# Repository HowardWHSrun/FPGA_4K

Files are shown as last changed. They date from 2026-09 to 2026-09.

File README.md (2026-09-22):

# FPGA_4K

Shared PCB development for the 4K neural-recording system: working designs, interface decisions, reference boards and acquisition software.

## Start working with the team

**[Team start page](docs/team/README.md)** · **[Setup and daily workflow](CONTRIBUTING.md)** · **[Owners and open work](docs/team/owners-and-work.md)**

| Work | Start here | Status |
|---|---|---|
| FPGA design | [Open the working draft](hardware/fpga-board/README.md) | Imported September 21; incomplete electrical design; **not for manufacture** |
| Carrier and routing boards | [Original reference projects](hardware/README.md) | Preserved references; active baselines and owners to confirm |
| Tasks and layout ownership | [Create a PCB task](https://github.com/HowardWHSrun/FPGA_4K/issues/new?template=pcb-task.yml) | One active layout editor per board |
| Pinout / power / protocol decisions | [Create a decision](https://github.com/HowardWHSrun/FPGA_4K/issues/new?template=interface-decision.yml) | Review with owners on both sides |
| Proposed changes | [Pull requests](https://github.com/HowardWHSrun/FPGA_4K/pulls) | Branch → review → merge → pull |

Use KiCad **10.0.6** for the FPGA handoff. Clone the repository, open the project from your clone, and keep its custom libraries alongside it. Follow [CONTRIBUTING.md](CONTRIBUTING.md) before editing; uploading a draft does not approve its circuit or make `main` fabrication-ready.

## Board overview

### Overall assembly

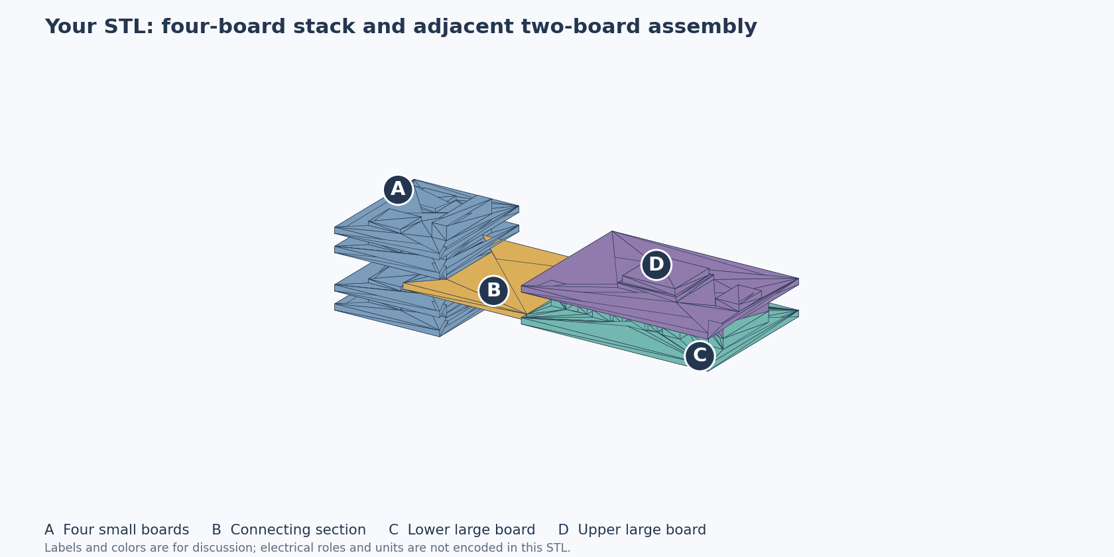
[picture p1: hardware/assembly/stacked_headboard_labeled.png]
Overall stacked-headboard assembly concept


The earlier assembly concept shows the four-board ASIC-carrier stack, routing section and FPGA board. **[Open the 3D model and region guide](hardware/assembly/README.md)** · [Download STL](hardware/assembly/stacked_headboard_original.stl?raw=true). The original model is preserved; dimensions are provisional and its author is unverified.

### Supplied board references

| ASIC carrier reference | LDO/routing reference |
|---|---|
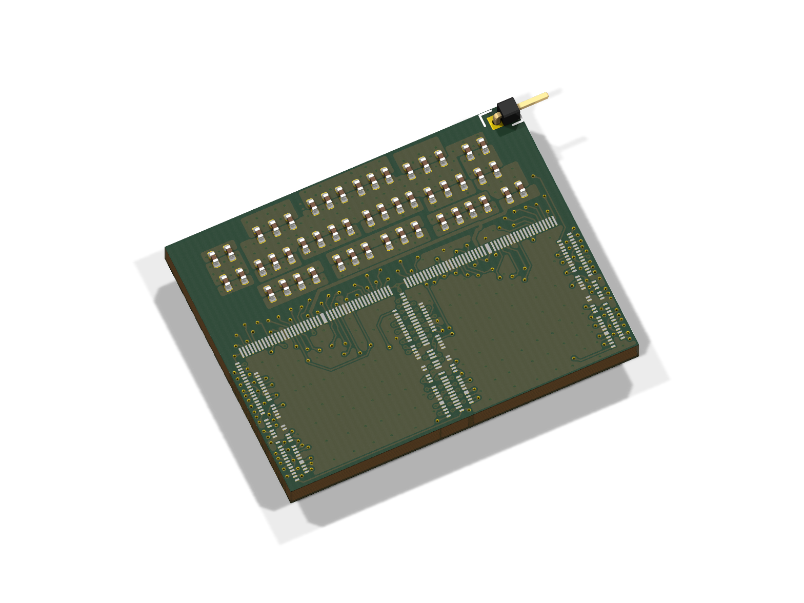
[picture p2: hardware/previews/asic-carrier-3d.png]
Overall view of the supplied two-chip carrier
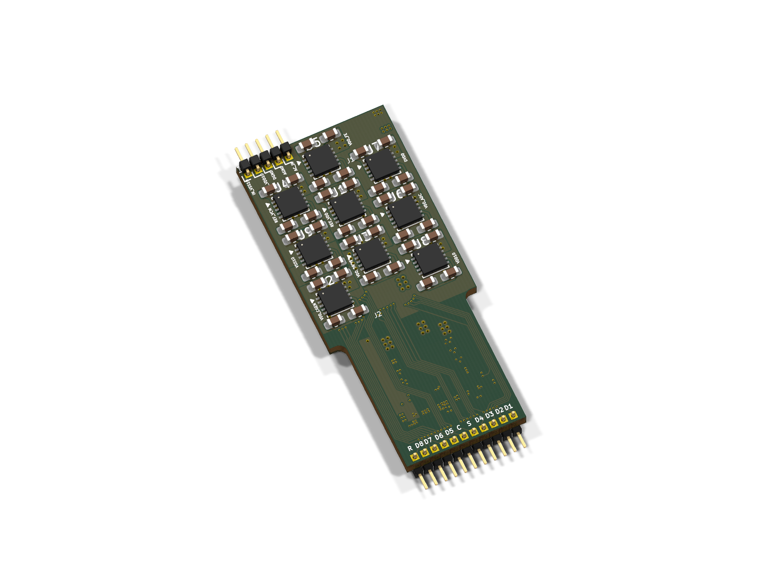
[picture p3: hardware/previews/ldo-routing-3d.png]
Overall view of the supplied LDO and routing board
|  |  |
| Approximately 22 × 17 mm; two chip footprints | Approximately 18.3 × 42 mm; regulator area and signal routing |

These are renders of the supplied reference boards; unavailable custom 3D models are omitted. Open the **[visual hardware overview](hardware/overview.md)** for the system diagram, original assembly photograph, front/back layouts and editable files. The two references do not represent a completed 4K assembly or a verified mating pair.

## Files

The files below are **included in this repository**. Click a filename to open it, or a download link to save it.

| Material | Files |
|---|---|
| Overall board and system views | [Visual overview](hardware/overview.md) · [Board images and vector layouts](hardware/previews/) · [Original assembly photograph in slide 2](sources/slides/previews/slide-02.png) |
| ASIC/interface slides — 28 slides | [PowerPoint](sources/slides/Chip_FPGA_Interface.pptx) · [Download PPTX](sources/slides/Chip_FPGA_Interface.pptx?raw=true) · [PDF](sources/slides/Chip_FPGA_Interface.pdf) · [Searchable text](docs/slides/asic-interface-text.md) |
| September 17 meeting | [PDF notes](sources/meetings/2026-09-17-notes.pdf) · [Download Word notes](sources/meetings/2026-09-17-notes.docx?raw=true) · [Read online](docs/meetings/2026-09-17.md) |
| ASIC carrier PCB | [KiCad project](hardware/references/asic-carrier/PCB.kicad_pro) · [Schematic](hardware/references/asic-carrier/PCB.kicad_sch) · [Board](hardware/references/asic-carrier/PCB.kicad_pcb) · [Pin spreadsheet](hardware/references/asic-carrier/Pins.xlsx?raw=true) |
| LDO/routing reference | [KiCad project](hardware/references/ldo-routing/PCB.kicad_pro) · [Schematic](hardware/references/ldo-routing/PCB.kicad_sch) · [Board](hardware/references/ldo-routing/PCB.kicad_pcb) |
| FPGA acquisition software | [Included source files](firmware/FPGA_512/) · [Source overview](firmware/README.md) · [Program guide](docs/software.md) |
| Project context and open questions | [Meeting questions](docs/meetings/2026-09-17.md#questions-to-resolve-in-the-next-review) · [Workstreams and interface notes](docs/meetings/2026-09-18-follow-up.md) |

For the full folder, use GitHub's **Code → Download ZIP** or clone the repository. [The document library](docs/library.md) provides a longer index.

## Project context

The recorded system path is **recording chips → routing board → FPGA board → KR260 → PC**. The meeting identifies the FPGA-to-receiver interface, complete signal map, power handoff and startup behavior as open requirements. Dates and uncertainty are retained in the meeting records.

The included FPGA_512 code is an earlier **ECP5/FT600** implementation. It provides acquisition RTL, host software and testbenches; it is not a completed 4K Artix-7 implementation.

## Working with the files

```sh
git clone https://github.com/HowardWHSrun/FPGA_4K.git
cd FPGA_4K
python3 scripts/check_docs.py
python3 scripts/check_hardware.py
```

The source files come with the clone—no separate source download is needed. The check requires Python 3.9+ and Git, and verifies local links and file hashes. See the [software guide](docs/software.md) for program entry points and the [hardware guide](hardware/README.md) for KiCad files.

AI agents should start with [AGENTS.md](AGENTS.md). Source credits, versions and copy details are recorded in [provenance](sources/README.md).

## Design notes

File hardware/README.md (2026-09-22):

# Hardware design files

This directory contains the editable [FPGA working draft](fpga-board/README.md), plus preserved ASIC-carrier and older LDO/routing references. No board in this collection is represented as an approved new-system fabrication package.

## Active FPGA working draft

Open [the project guide](fpga-board/README.md), then the [KiCad project](fpga-board/hardware/Howard_FPGA_Connected_42x40.kicad_pro). All child sheets and local libraries are included. Use the [team workflow](../CONTRIBUTING.md) and [ownership register](../docs/team/owners-and-work.md). The draft's electrical and manufacturing work remains incomplete.

## Supplied references

Start with the **[visual hardware overview](overview.md)**: overall board views, front/back layouts, an original assembly photograph and the system signal path. [PNG and SVG files](previews/README.md) are included for viewing without KiCad.

The earlier **[overall assembly concept](assembly/README.md)** is also included as an unchanged STL with a labeled preview. It shows the carrier stack, routing section and FPGA-board arrangement; its dimensions remain provisional.

## ASIC carrier PCB-5

- [KiCad project](references/asic-carrier/PCB.kicad_pro)
- [Schematic](references/asic-carrier/PCB.kicad_sch)
- [Board](references/asic-carrier/PCB.kicad_pcb)
- [Original pin-planning spreadsheet](references/asic-carrier/Pins.xlsx)

The provided files declare KiCad 10. The saved schematic and board include embedded symbols/footprints. A complete separate custom carrier library was not supplied in this collection; obtain it from the designer if editing requires new or updated custom instances. The spreadsheet is retained as supplied, without promoting it to an approved connector specification.

## LDO/routing reference

- [KiCad project](references/ldo-routing/PCB.kicad_pro)
- [Schematic](references/ldo-routing/PCB.kicad_sch)
- [Board](references/ldo-routing/PCB.kicad_pcb)
- [Supplied connector-footprint library](references/ldo-routing/LDO_Board.pretty/)

The older source declares KiCad 9. Its circuit/project files are unchanged copies. The footprint-library table has one documented adaptation: the original workstation path points to the included local library using `${KIPRJMOD}`. Keep the directory together when opening it.

Use a compatible KiCad installation and a working copy for format migrations. The reference projects are not a verified mating pair. Authoritative pin, electrical, power and mechanical requirements must come from the designers.

The [September 17 meeting](../docs/meetings/2026-09-17.md) records the chip and older routing/LDO examples. [Source provenance](../sources/README.md) and [the manifest](../sources/manifest.json) identify their origin, preserved source paths and hashes.

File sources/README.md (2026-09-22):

# Source provenance

The project files are stored in this repository. Attribution and copy details are recorded here so the main documentation can focus on the system and its interfaces.

| Material | Source and representation |
|---|---|
| ASIC/interface PowerPoint | Deck supplied by Gerald; unchanged original file |
| Slide PDF, searchable text and PNG previews | Representations of the original deck; diagrams remain available in the PPTX/PDF |
| Carrier PCB-5 and Pins.xlsx | Chip-side reference files shared for the project; unchanged copies |
| LDO/routing project and connector footprints | Shared reference files; unchanged except the library-table path adaptation below |
| Overall board renders and front/back layouts | Generated directly from the included carrier and LDO/routing CAD; [rendering details](../hardware/previews/README.md). No new board design is introduced |
| Overall assembly STL and labeled preview | Original user-supplied `stacked_headboard_onebody (1).stl`, preserved unchanged as `hardware/assembly/stacked_headboard_original.stl`, plus the existing labeled preview from the September 18 review. Included at the user's explicit request; original author unverified, not attributed to Gerald. [Assembly guide](../hardware/assembly/README.md) |
| September 17 DOCX/PDF notes | Summary prepared from the recorded team meeting; not a verbatim transcript |
| September 18 follow-up | Technical summary of team messages; received date is known, individual message dates were not provided |
| FPGA_512 code | Snapshot of [gt-ic/FPGA_512](https://github.com/gt-ic/FPGA_512/tree/767e82528780005cbcb37b3e926197755bac622e), shared as the prior acquisition reference; [included files and packaging details](../firmware/README.md) |

[manifest.json](manifest.json) records each imported file's origin, size and SHA-256. Origins identify source revisions or archive labels; they are not paths required on a collaborator's computer.

The LDO library table uses `${KIPRJMOD}/LDO_Board.pretty` in place of its original workstation path. `source_sha256` retains the original hash; the circuit files are unchanged. Included upstream program files retain their original bytes and notices. Upstream repository metadata and local caches are not part of the source copy.

The collection now also includes the [FPGA working draft](../hardware/fpga-board/README.md), imported at the user's request for team development. Its [baseline and snapshot evidence](fpga-draft-2026-09-21/README.md) distinguish the editable design from historical sources. Native CAD and local libraries were copied unchanged; Git tracks later edits. The immutable manifest covers the import record and selected evidence, not the evolving CAD files. Private chat/audio, unrelated personal material, experimental generators, rejected candidates, caches and hidden histories remain outside the shared package.

The photograph in the [hardware overview](../hardware/overview.md) is the complete second slide of the included interface deck, rendered from its PDF. It shows a single-chip assembly; it is not labelled as the two-chip PCB-5 CAD revision. The system diagram summarizes the dated meeting record. The reference-board CAD views and the separately supplied overall arrangement STL are distinct sources; their inclusion does not establish that the reference boards mechanically mate.

Original ownership and applicable terms are retained. No repository-wide license was found in the pinned FPGA_512 tree; this collection adds no license grant to that code or the imported lab material.

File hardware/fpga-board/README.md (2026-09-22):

# FPGA board — working draft

**PARTIAL DESIGN — NOT FOR MANUFACTURE.** This is the saved local FPGA draft imported for team collaboration on 2026-09-21, not an approved circuit or a fabrication release. Review and accept the baseline before extending it.

**[Open the KiCad project](hardware/Howard_FPGA_Connected_42x40.kicad_pro)** · [Main schematic](hardware/Howard_FPGA_Connected_42x40.kicad_sch) · [PCB layout](hardware/Howard_FPGA_Connected_42x40.kicad_pcb) · [Team workflow](../../CONTRIBUTING.md)

Use KiCad **10.0.6** for this handoff. Open the `.kicad_pro` through KiCad Project Manager. The complete 41-sheet hierarchy, local symbol library and local footprint library are included. Keep `hardware/` and `libraries/` together. Standard model references use KiCad's installed 3D library; complete custom mechanical models are not supplied.

## Layout at import

| Front copper and fabrication layer | Back copper and fabrication layer |
|---|---|
| FPGA front layout | FPGA back layout mirrored |

Generated from the imported board with KiCad 10.0.6; back view is mirrored. These dated outer-layer views omit inner copper and do not demonstrate routing completion. Regenerate previews for layout changes.

## Initial saved state

The imported PCB is 42 × 40 mm with 214 positions, 703 track segments, 128 vias and six filled zones. The 22-net programming signal scope is routed, and selected supply/ground fanouts are present. Power-converter loops, complete power delivery, application pin assignments and qualification remain unfinished.

The September 21 source reports record **270 remaining PCB connection items**, **661 unresolved schematic pins**, and **21 undriven power pins**. Their zero general DRC violations and zero schematic parity issues apply only to the enabled rules; they do not mean the design is complete. Some schematic IC pin types are generic passive and need manufacturer-pin-function review.

See the [snapshot evidence and disabled-rule list](../../sources/fpga-draft-2026-09-21/README.md), [draft BOM](../../sources/fpga-draft-2026-09-21/BOM_Draft.csv) and [unresolved pin ledger](../../sources/fpga-draft-2026-09-21/Unresolved_Pin_Ledger.csv). These are dated import artifacts. Regenerate reports and BOMs for later commits rather than treating them as live design outputs.

## Before editing

Claim layout ownership in a PCB task; see [owners and open work](../../docs/team/owners-and-work.md). Use a branch and review the change in a pull request. Edit these native files directly. Historical experimental generators and rejected routing candidates are deliberately not included: rerunning an old generator could overwrite reviewed CAD.

Current unknowns include RAM/controller, connector pin maps and IO levels, receiver protocol, oscillator, rail budgets/compensation, remaining FPGA pin treatment, stackup, impedance, mechanical fit and assembly rules. Keep each as `TBD + owner` until a reviewed decision closes it.

The 0.10 mm minimum clearance, 0.15 mm routing traces and 0.50/0.20 mm vias are draft capabilities requiring fabricator agreement. The ADP5052 footprint and power-loop design require review. The R112 near-pad via needs assembler mask/tenting review; L1 placement and the C84 analog bypass proposal also need electrical/mechanical qualification.

## Files and history

`hardware/` holds the editable KiCad project, all child sheets and project library tables. `libraries/` holds its custom symbols and footprints. The [import baseline](../../sources/fpga-draft-2026-09-21/import-baseline.json) records original paths and hashes; subsequent changes belong in Git history. This working copy is separate from the immutable supplied boards in [references](../README.md).

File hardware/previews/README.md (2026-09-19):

# Board preview files

Open the [visual hardware overview](../overview.md) for captions, the system diagram and links to the original designs.

| Supplied design | Overall view | Front layout | Back layout |
|---|---|---|---|
| ASIC carrier PCB-5 | [3D PNG](asic-carrier-3d.png) | [PNG](asic-carrier-front.png) · [SVG](asic-carrier-front.svg) | [PNG](asic-carrier-back.png) · [SVG](asic-carrier-back.svg) |
| LDO/routing reference | [3D PNG](ldo-routing-3d.png) | [PNG](ldo-routing-front.png) · [SVG](ldo-routing-front.svg) | [PNG](ldo-routing-back.png) · [SVG](ldo-routing-back.svg) |

## What the images contain

These views were generated on September 19, 2026 from the unchanged [carrier PCB](../references/asic-carrier/PCB.kicad_pcb) and [LDO/routing PCB](../references/ldo-routing/PCB.kicad_pcb), using KiCad 10.0.6. Input and output hashes are recorded in the [source manifest](../../sources/manifest.json).

- **3D views:** complete board outline and the component models available to KiCad, viewed from the front at an angle. Missing custom models, including the ASIC bodies, are not invented. These are visualizations of the saved CAD, not assembly photographs or a validated bill of materials.
- **Front/back layouts:** the selected outer copper layer, silkscreen and board outline. Carrier views also include fabrication-layer footprint outlines. LDO fabrication text is omitted because overlapping value labels obscure the layout. Internal copper layers are available in the original CAD.
- **Orientation:** back layouts are mirrored so they are viewed from the back of the board. Front copper is red, back copper is blue. Images of different boards are independently fitted and are not to a common scale.
- **Original photograph:** [slide 2](../../sources/slides/previews/slide-02.png) preserves the full presentation page, including the assembled single-chip carrier and bond-wire close-up. It is a different source example from the two-chip PCB-5 reference.

## Reproducing the views

Run from the repository root with `kicad-cli` on your path. The example below writes to an ignored local folder, preserving the published images and original CAD:

```sh
mkdir -p tmp/board-previews
for board in asic-carrier ldo-routing; do
  kicad-cli pcb render \
    --width 1600 --height 1200 --side top \
    --background transparent --quality high \
    --rotate '335,0,25' --zoom 0.65 \
    --output "tmp/board-previews/$board-3d.png" \
    "hardware/references/$board/PCB.kicad_pcb"

  front_layers='F.Cu,F.Silkscreen,Edge.Cuts'
  back_layers='B.Cu,B.Silkscreen,Edge.Cuts'
  if [ "$board" = asic-carrier ]; then
    front_layers='F.Cu,F.Silkscreen,F.Fab,Edge.Cuts'
    back_layers='B.Cu,B.Silkscreen,B.Fab,Edge.Cuts'
  fi
  kicad-cli pcb export svg --layers "$front_layers" \
    --mode-single --page-size-mode 2 --exclude-drawing-sheet \
    --output "tmp/board-previews/$board-front.svg" \
    "hardware/references/$board/PCB.kicad_pcb"
  kicad-cli pcb export svg --layers "$back_layers" --mirror \
    --mode-single --page-size-mode 2 --exclude-drawing-sheet \
    --output "tmp/board-previews/$board-back.svg" \
    "hardware/references/$board/PCB.kicad_pcb"
done
```

KiCad's installed model libraries, color theme and version affect appearance. No zone refill, source migration or circuit edit was performed. The saved SVGs retain the native vector output. PNG layout previews were rasterized using Sharp 0.35.4, fitted within 1800 × 2400 pixels, with a `#17212b` background and a 40-pixel border. They can be reproduced with Sharp available to Node.js:

```js
const sharp = require('sharp');

async function renderLayouts() {
  for (const board of ['asic-carrier', 'ldo-routing']) {
    for (const side of ['front', 'back']) {
      const base = `tmp/board-previews/${board}-${side}`;
      await sharp(`${base}.svg`)
        .resize({ width: 1800, height: 2400, fit: 'inside' })
        .flatten({ background: '#17212b' })
        .extend({ top: 40, bottom: 40, left: 40, right: 40,
                  background: '#17212b' })
        .png().toFile(`${base}.png`);
    }
  }
}
renderLayouts().catch(error => { console.error(error); process.exitCode = 1; });
```

The full-slide photograph preview was rendered with Poppler 26.05.0:

```sh
pdftoppm -f 2 -singlefile -scale-to 1400 -png \
  sources/slides/Chip_FPGA_Interface.pdf tmp/board-previews/slide-02
```

Re-rendering supports documentation. It does not run an electrical, fabrication or hardware validation.

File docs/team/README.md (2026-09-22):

# Team start page

This repository is the shared working location for PCB design, interface decisions and reference material. Begin with the [contribution guide](../../CONTRIBUTING.md).

| I want to… | Open |
|---|---|
| Get the files and make a change | [Setup and daily workflow](../../CONTRIBUTING.md) |
| Open the active FPGA CAD | [FPGA working draft](../../hardware/fpga-board/README.md) |
| Find who owns a board or a decision | [Owners and open work](owners-and-work.md) |
| Propose a task or claim layout work | [New PCB task](https://github.com/HowardWHSrun/FPGA_4K/issues/new?template=pcb-task.yml) |
| Record a pinout, power or protocol decision | [Interface decision template](https://github.com/HowardWHSrun/FPGA_4K/issues/new?template=interface-decision.yml) |
| Review a proposed change | [Pull requests](https://github.com/HowardWHSrun/FPGA_4K/pulls) |
| See the original boards and meeting material | [Document library](../library.md) |

## Administrator setup

The repository is public. Collaborators need an invitation for push access: open [Settings → Collaborators](https://github.com/HowardWHSrun/FPGA_4K/settings/access), choose **Add people**, and enter each teammate's GitHub username. Usernames and accepted responsibilities have not yet been supplied; the ownership table intentionally leaves them TBD.

Use one approving review and the `documentation` repository check for `main`; block force pushes and branch deletion. This check covers documentation and CAD packaging, not electrical correctness. Repository protection does not assign engineering responsibility. Keep administrative bypass available for repository recovery, not routine design review.

## First team session

1. Assign the FPGA layout owner and reviewer, plus owners for carrier, routing/power, receiver and firmware work.
2. Confirm the imported FPGA draft is the starting candidate or record the agreed replacement. Importing it does not constitute engineering approval.
3. Each teammate clones and opens the project successfully with the agreed KiCad version.
4. Put the next concrete task in an issue. Run one small change through branch, pull request, review and handoff.

There is one integrated FPGA working copy here. The earlier local study is the import source; edits to that external folder will not automatically appear in GitHub. New team work should use the cloned repository project.

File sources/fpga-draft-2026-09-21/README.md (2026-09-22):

# FPGA draft import evidence — 21 September 2026

**PARTIAL DESIGN — NOT FOR MANUFACTURE.** These are historical records for the initial [working FPGA project](../../hardware/fpga-board/README.md). They do not automatically update when the CAD changes.

## Provenance and scope

Source: Howard's saved `Howard_PCB_Size_Study/FPGA_PCB_Connected` project, developed locally with AI assistance. This is an independent engineering draft, not an original board supplied or approved by another designer. Imported at Howard's request to support team PCB collaboration. Engineering review and qualification remain pending.

[import-baseline.json](import-baseline.json) records the source label, size and SHA-256 of each of the 286 native CAD and library files. All were copied byte-for-byte. The current CAD is editable; keep this initial record unchanged and use Git history for later revisions.

Selected source reports and ledgers were copied below. Workstation-specific source-directory prefixes, if present, were replaced with the relative source label; source and published hashes are recorded in the main manifest. Excluded: lock/preferences files, backups, rejected candidate boards, experimental generators, private chat/audio and unrelated personal material. The package contains the saved editable design, not its historical generation environment. Required custom symbols and footprints are included; standard 3D models depend on a normal KiCad library installation.

## Verification

Native KiCad 10.0.6 checks were rerun on the repository copy: **0 general DRC violations, 270 unconnected items, 0 schematic parity issues; ERC: 661 unconnected pins and 21 undriven power pins**. See [handoff-verification.json](handoff-verification.json). The original [DRC](routed_drc.json) and [ERC](erc.json) reports describe the same known outstanding work.

The following categories were already disabled in the source project and remain unchanged:

- DRC: `footprint_filters_mismatch`, `footprint_type_mismatch`, `missing_courtyard`, `track_not_centered_on_via`, `tuning_profile_track_geometries`.
- ERC: `footprint_filter`, `four_way_junction`, `simulation_model_issue`, `single_global_label`.

These results apply only to enabled checks. Generic passive IC pin types further limit ERC. Clear geometry does not prove correct pin functions, continuous power delivery, timing, SI/PI, thermal performance or manufacturability.

## Dated engineering ledgers

- [Draft BOM](BOM_Draft.csv): candidate values/order codes and unresolved qualification; not an approved procurement list.
- [Unresolved pin ledger](Unresolved_Pin_Ledger.csv): open pin assignments at import.
- [Filled-copper reachability](filled_connectivity_20260921.json): reaching matching plane copper does not prove every island is joined or a regulator operates.

The source board hash is `0c7fcd69af90aed69761398ca1ac4edc06444f5968559bccd5eedfdd4ae280b3`. Regenerate evidence for subsequent commits. No fabrication output is included.

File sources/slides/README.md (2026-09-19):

# ASIC/interface slides

- [Download the original PowerPoint](Chip_FPGA_Interface.pptx?raw=true)
- [Open the PDF](Chip_FPGA_Interface.pdf)
- [Read searchable slide text](../../docs/slides/asic-interface-text.md)

The complete 28-slide deck is included. The PDF and selected PNG previews are alternate representations for reading the same material.

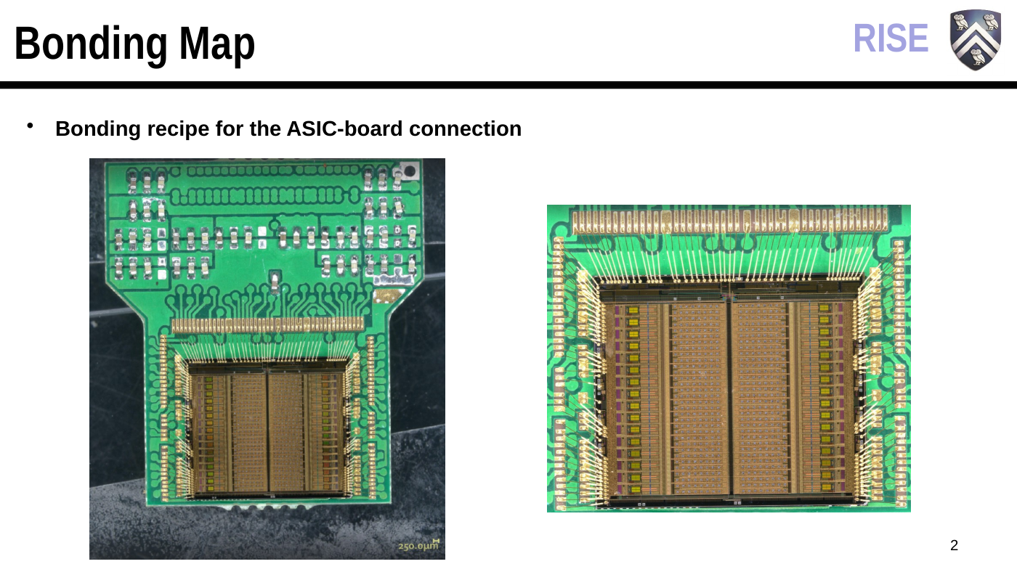
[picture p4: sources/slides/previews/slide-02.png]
Slide 2: assembled chip carrier and wire-bond close-up


[Overall board views and system context](../../hardware/overview.md)

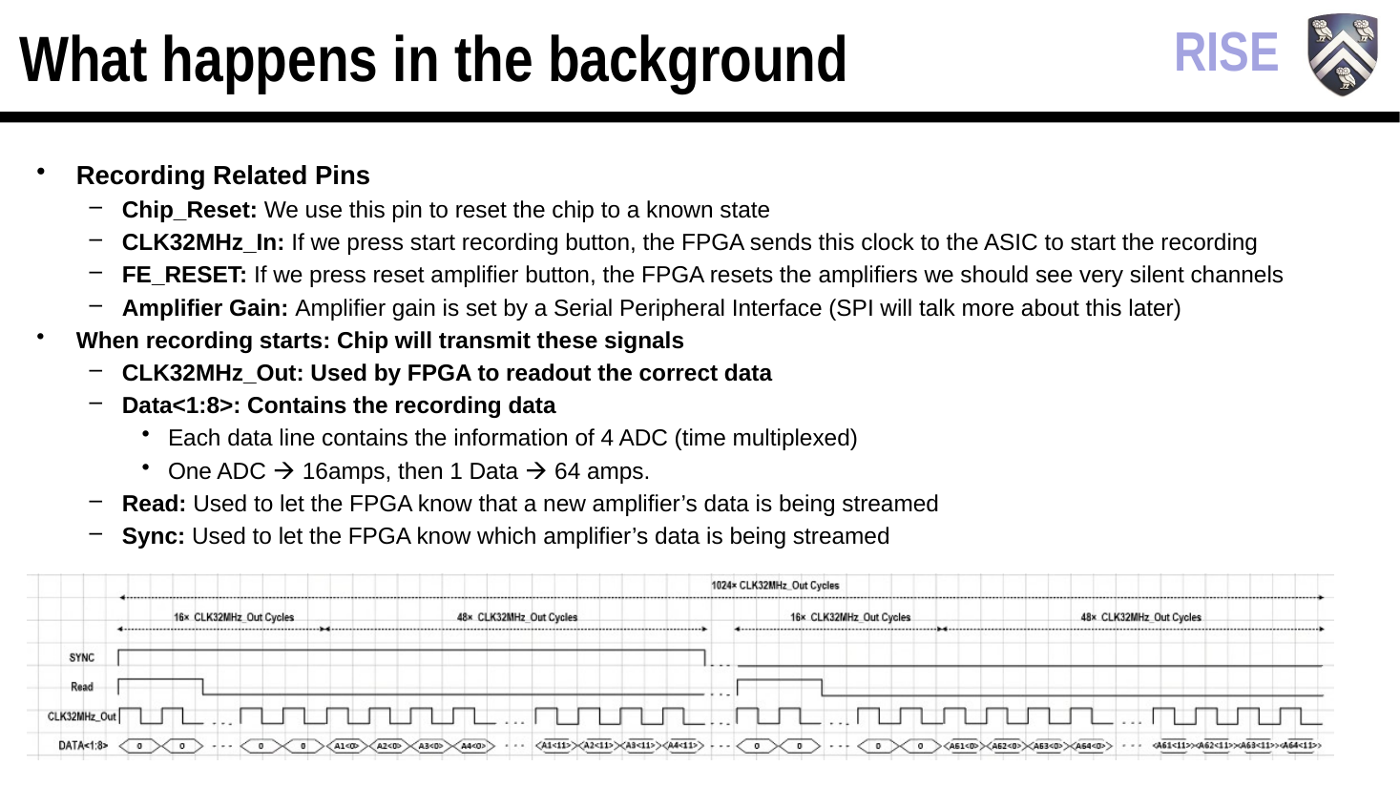
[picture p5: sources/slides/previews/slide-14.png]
Slide 14: recording signals and timing


[Source credits and file checksums](../README.md)

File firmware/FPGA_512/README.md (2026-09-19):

# FPGA_512 — 512-Channel ADC Acquisition Pipeline

A Lattice ECP5 FPGA design plus host software that streams **512 neural-probe
channels at 15,625 Hz** off an ADC board, over USB 3.0 (FT600), into a host
daemon that decodes, records, and plots the data live.

---

# Part 1 — The Live Visualizer

The visualizer is a real-time 8-panel scope with an attached command terminal.
`adc_daemon` (C) owns the USB device and decodes frames; `adc_live.py` (Python)
connects to it over a Unix socket and draws the scrolling plot.

```
FT600 USB ──► adc_daemon ──► /tmp/adc_daemon.sock ──► adc_live.py (plot + terminal)
                    │                              └─► adc_ctl (one-shot CLI)
                    └──► WAV recording
```

## Prerequisites

| Dependency | Purpose | Install |
|---|---|---|
| libftd3xx  | FT600 USB driver | [FTDI D3XX](https://ftdichip.com/drivers/d3xx-drivers/) — put `libftd3xx.dylib` in `/usr/local/lib`, `ftd3xx.h` in `/usr/local/include` |
| gcc/clang  | C compiler | Xcode CLI tools (macOS) / `build-essential` (Linux) |
| Python 3 + numpy + matplotlib | Live UI | `pip3 install numpy matplotlib` |

## Build and launch

```bash
cd adc_4lane_framed
make adc_daemon adc_ctl

./live.sh            # starts the daemon, launches the UI, cleans up on exit
```

`live.sh` kills any stale daemon, starts a fresh one, waits for it to come up,
then runs `adc_live.py`. Closing the plot window shuts the daemon down.

To run the two halves separately (useful when debugging):

```bash
./adc_daemon &                 # live hardware
./adc_daemon --file cap.bin    # or: replay a raw capture in a loop, no hardware
python3 adc_live.py
```

**No hardware?** See [`adc_4lane_framed/FRONTEND_DEV.md`](adc_4lane_framed/FRONTEND_DEV.md)
— the daemon replays a recorded capture at real-time pace and serves the exact
same socket API, so the UI and any other frontend work unchanged.

## What you see

A 4x2 grid of panels, one per data line **D1–D8**. Each line carries 64
amplifiers (electrodes); by default amps **0, 31, 63** are plotted per line, so
8 panels x 3 traces = 24 of the 512 channels at once.

- **X axis** — seconds, scrolling right-to-left, 1 s window by default.
- **Y axis** — volts, input-referred (`volts = pcm * 4.5776e-6`), full scale
  ±15.36 mV. Autoscales with hysteresis unless you pin it with `ylim`.
- Traces use the daemon's **peak-detect (minmax) mode**: each screen pixel shows
  the min *and* max of every full-rate sample behind it, so fast signals show
  their true envelope instead of aliasing into nonsense.

## Terminal commands

Type in the terminal that launched the UI. `help` lists everything.

### Local (change what the plot shows)

| Command | Effect |
|---|---|
| `chan D5:0,31,63` | Set which amplifiers (0–63) are plotted for line D5 |
| `chan all:0,16,32,48` | Same amp selection on every line |
| `ylim 2.5` | Pin the y range to ±2.5 mV (disables autoscale) |
| `ylim auto` | Re-enable y autoscale (default) |
| `win 5` | Scroll window length in seconds (0.05–60) |
| `single` | Freeze on a full-rate slice: finds the dominant frequency and shows 10 periods of it |
| `single 0.01` | Freeze on exactly 10 ms of full-rate data |
| `run` | Resume scrolling after `single` |
| `exit` / `q` | Quit UI and daemon |

`single` is the "stop scrolling and actually look at the waveform" command — the
scroll view is decimated 8x, `single` pulls undecimated samples.

### Passed through to the daemon

| Command | Effect |
|---|---|
| `cmd chip-reset` | Pulse ADC chip reset |
| `cmd fe-pulse` / `fe-on` / `fe-off` | Front-end reset: pulse / hold high (test mode, outputs midscale) / release to normal |
| `cmd pattern-on` / `pattern-off` | Swap real ADC data for a +1 ramp test pattern, and back |
| `cmd spi` | Run the built-in SPI init sequence |
| `cmd spi-load <csv>` | Load an arbitrary SPI bit pattern from CSV (`BIT,L,R`) |
| `cmd stim <1-255>` | Fire N stimulation pulses |
| `record start <path> <chans>` | Record to WAV; `chans` = `all` or `0-63,320,384-447` |
| `record stop` | Stop and report slices / errors / drops |
| `stats` | Throughput, ring fill, per-lane frame/CRC/seq/drop counters |
| `quit` | Shut the daemon down |

Async events print as they arrive, prefixed with `!`:

```
!drops lane=2 n=5 total=37     FPGA-side FIFO overflow (host fell behind)
!crc lane=0 total=3            CRC-12 mismatch
!seq lane=1 total=2            Missing frame
```

Anything the daemon accepts can also be sent one-shot without the UI:

```bash
./adc_ctl stats
./adc_ctl cmd fe-off
./adc_ctl record start /tmp/rec.wav 320-383
```

## Channel numbering

```
channel = line * 64 + amplifier          line = D1..D8 minus 1, amp = 0..63

D1 →   0- 63   D2 →  64-127   D3 → 128-191   D4 → 192-255
D5 → 256-319   D6 → 320-383   D7 → 384-447   D8 → 448-511
```

One *slice* = one sample from all 512 channels = one full amplifier sweep,
delivered 15,625 times per second.

## Writing your own frontend

The daemon is UI-agnostic. Send `plot <chans> <decim> [minmax]` on the socket
and the connection switches to a binary stream of `"ADCP"`-tagged packets.
Full protocol, packet layout, and a Python parsing example are in
[`adc_4lane_framed/FRONTEND_DEV.md`](adc_4lane_framed/FRONTEND_DEV.md).

## Troubleshooting

| Symptom | Cause |
|---|---|
| `cannot connect /tmp/adc_daemon.sock` | Daemon isn't running — start `./adc_daemon` or use `live.sh` |
| `FT_Create failed (device busy?)` | Another tool holds the FT600. Only one process at a time |
| Flat lines at 0 V | Front end held in reset — send `cmd fe-off` |
| Staircase-looking waveforms | Host isn't keeping up; check `stats` for nonzero `drops` |
| `!seq` events once per loop in replay mode | Normal — the capture file wrapped |

---

# Part 2 — The Repository

## Signal path

```
ADC board ──8 serial lines + 32 MHz clock──► ECP5 FPGA ──USB 3.0──► host
                                                  │
   deserialize → 4 framed lanes → arbiter → USB framer → async FIFO → FT600
                                                  └──► UWB serial mirror (J6)
```

The FPGA deserializes 8 bit-interleaved ADC streams, packs them into four
132-word framed lanes (SYNC / LANE_ID / CYCLE_CNT / 128 data words / CRC-12),
round-robins the lanes into one USB stream, and buffers through a 64 KB BRAM
elastic FIFO into the FT600. Sustained rate is **16.5 MB/s**.

## Layout

| Path | Contents |
|---|---|
| `fpga/` | Verilog modules: `adc_auto_adjust`, `pair_tdm_framer`, `lane_frame_arbiter`, `usb_framer`, `async_fifo`, `ft600_writer`, `spi_programmer`, `stim_controller`, `serial_framer`, top levels, `.lpf` constraint files |
| `decoder/` | `UWB_Serial_Handler.v` — downstream serial output handler |
| `adc_4lane_framed/` | **Main design.** Top level `top_4lane_framed.v` + all host tools (daemon, live UI, recorders, benchmarks) |
| `adc_2ch_framed/` | Earlier 2-channel framed design, kept as a reference point |
| `adc_channel_test/`, `adc_auto_adjust_test/`, `pll_test/`, `led_blink/`, `ft600_test/`, `spi/`, `bringup/` | Bring-up and unit-test designs, each with its own Makefile |
| `FPGA_UWB/`, `FPGA_UWB_STATIC/` | Standalone UWB-header designs: 16→64 MHz ECP5 PLL driving a 4-bit output, either free-running (`FPGA_UWB`) or fixed at build time (`FPGA_UWB_STATIC`, `make VALUE=9`) |
| `UWB_SPI/` | Host-side bit-banged SPI to the UWB chip over an MCC DAQ device, plus the vendored `mcculw` examples it depends on |
| `sim/`, `sim_tb*` | Icarus testbenches, ADC models, waveform-comparison scripts |
| `docs/` | `SYSTEM_OVERVIEW.md` (full data path, stage by stage), `FRAMING_SPEC.txt` (wire format), board pinouts |
| `golden_bitstreams/` | Hardware-verified `.bit` files, archived deliberately (rest of the build output is gitignored) |
| `analysis/`, `scripts/`, `receiver/` | Capture analysis, HDF5 → pattern-generator conversion, Python receiver |

## Host tools (`adc_4lane_framed/`)

| Tool | Purpose |
|---|---|
| `adc_daemon` | Continuous receiver. USB reader thread → 256 MB ring → decoder thread → WAV recording + publish ring + socket server |
| `adc_ctl` | One-shot CLI for a running daemon |
| `adc_live.py` | Live scope UI (Part 1) |
| `live.sh` | Launcher for daemon + UI |
| `wave_record` | Standalone WAV recorder with frame validation and read-gap histogram |
| `usb_capture` | Dumps the raw USB byte stream to a file (feeds `--file` replay) |
| `pattern_check` | Validates the ramp test pattern end to end |
| `lane_test`, `board_cmd`, `usb_bench`, `thread_drop_test` | Lane decode check, board opcodes, throughput benchmark, drop reproducer |
| `capture_plot.py` | Offline plotting of recorded captures |

## Building the bitstream

Requires [oss-cad-suite](https://github.com/YosysHQ/oss-cad-suite-build) at
`/opt/oss-cad-suite` (Yosys → nextpnr-ecp5 → ecppack).

```bash
cd adc_4lane_framed
make synth      # bitstream only
make flash      # program SPI flash via dirtyJtag (LFE5U-25F)
```

Synthesis is split around `opt -undriven` because that pass removes the DP16KD
block-RAM cells the FIFOs depend on — see the comment in the Makefile before
changing it.

**Target:** LFE5U-25F-7BG256I, CABGA256, speed grade 7. Use `make flash`, not
SRAM programming.

## Key numbers

```
Sample rate     15,625 Hz per channel        Channels        512 (8 lines x 64 amps)
Resolution      12-bit ADC → 16-bit PCM      USB throughput  16.5 MB/s
PCM encoding    pcm = (adc - 2048) << 4      Volts/count     4.5776e-6
Full scale      ±15.36 mV input-referred     CRC             CRC-12 ITU-T, poly 0x80F
Frame           132 words (128 data)         Lanes           4, frame-interleaved
```

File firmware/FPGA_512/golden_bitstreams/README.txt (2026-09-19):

Golden (known-good) bitstreams
==============================

adc_auto_adjust_test_KNOWN_GOOD.bit
-----------------------------------
Per-data-line independent test with automatic leading-zero detection (11-13).
8x adc_auto_adjust (sr_full version) -> 8x sync_fifo -> round-robin arbiter
-> {ch_id[3:0], sample[11:0]} raw words over FT600.

Built:    2026-07-21 16:41 from adc_auto_adjust_test/ (sr_full adc_auto_adjust.v)
Verified: all 8 channels PASS at midscale (mean ~2048, stddev 7-9) on hardware
          after ADC board power cycle.
SHA1:     5050228b878c83211bf9874444753967f1911624

Flash:
  /opt/oss-cad-suite/bin/openFPGALoader -c dirtyJtag --fpga-part LFE5U-25F -f \
      golden_bitstreams/adc_auto_adjust_test_KNOWN_GOOD.bit

Test (host reader sends start cmd 0x0100, reads N MB, per-channel stats):
  cd adc_auto_adjust_test && ./auto_adjust_test 5

Pass criteria per channel: mean in [1900,2200], stddev < 100.

Failure signature of a bad ADC-board state (NOT the FPGA/bitstream):
  all channels min=0 / max=4094, stddev > 1000 -> power cycle the ADC board.

adc_2ch_framed_KNOWN_GOOD.bit
-----------------------------
Pair-at-a-time framed pipeline: 8x adc_auto_adjust (all running) -> USB
command selects pair (0-3) -> 2ch strict-alternation TDM with valid/hold
handshake -> usb_framer (SYNC=0xA35, LANE=0, 132-word frames, CRC-12)
-> async_fifo -> FT600. Full production frame protocol over one lane.

Key fixes baked in (vs earlier failing builds):
  - usb_framer out_valid is combinational (= emitting); a registered
    out_valid drops the SYNC word and the host finds 0 frames.
  - Negedge first-stage capture of cb_d/cb_read: posedge sampling lands on
    the midscale MSB transitions (ADC0/ADC3 slots) in some placements,
    causing MSB drops on those slots only.

Built:    2026-07-22 from adc_2ch_framed/ (top_2ch_framed.v)
Verified: all 4 pairs / 8 channels PASS on hardware (stddev 7.0-8.8,
          0 CRC errors, 0 sequence gaps, ~7944 frames per pair).
SHA1:     7378e303a9c51ca9558f31bf7048b218910e801e

Flash:
  /opt/oss-cad-suite/bin/openFPGALoader -c dirtyJtag --fpga-part LFE5U-25F -f \
      golden_bitstreams/adc_2ch_framed_KNOWN_GOOD.bit

Test (cycles all 4 pairs, N MB each, frame decode + CRC + per-channel stats):
  cd adc_2ch_framed && ./pair_test 2

Pass criteria per channel: mean in (1900,2200), stddev < 100, 0 CRC errors.

adc_4lane_framed_KNOWN_GOOD.bit
-------------------------------
Full 4-lane production pipeline: 8x adc_auto_adjust -> 4x pair_tdm_framer
(SYNC 0xA35/0xB46/0xC57/0xD68, LANE 0-3, sample FIFO depth 64) ->
frame-granular round-robin arbiter -> async_fifo -> FT600. All 8 channels
stream continuously; every frame self-labelled by SYNC + LANE_ID, host
demuxes by lane. 33 MB/s sustained over USB.

Key fix beyond the pair build: memory writes moved out of async-reset
processes (sync_fifo mem, usb_framer dbuf) so yosys infers LUTRAM instead
of one-FF-per-bit — utilization dropped from 98% (unplaceable; also the
root cause of the old "93% LUT" full-pipeline failures) to ~13%.

Built:    2026-07-22 from adc_4lane_framed/ (top_4lane_framed.v)
Verified: all 4 lanes / 8 channels PASS simultaneously on hardware
          (stddev 7.0-8.7, 0 CRC / 0 seq / 0 lane_id errors,
          ~7950 frames per lane over 8 MB).
SHA1:     420d958c00ab63456e2851cc236bdb4916964e44

Flash:
  /opt/oss-cad-suite/bin/openFPGALoader -c dirtyJtag --fpga-part LFE5U-25F -f \
      golden_bitstreams/adc_4lane_framed_KNOWN_GOOD.bit

Test (reads N MB, demuxes 4 lanes, CRC + per-channel stats):
  cd adc_4lane_framed && ./lane_test 8

Pass criteria per channel: mean in (1900,2200), stddev < 100, 0 CRC errors.

adc_4lane_cmd_KNOWN_GOOD.bit
----------------------------
Same 4-lane pipeline as adc_4lane_framed_KNOWN_GOOD.bit, plus host-
controlled resets. BOOTS IN REAL-DATA MODE (CB_FE_RESET low), so a fresh
power-up reads live amplifier data, NOT midscale. Command byte on pipe
0x02 (send with adc_4lane_framed/board_cmd):
  0x11 chip-reset : pulse CB_CHIP_RESET (~62 ns)
  0x21 fe-pulse   : pulse CB_FE_RESET
  0x22 fe-on      : hold CB_FE_RESET high (test mode -> ~2048 midscale)
  0x23 fe-off     : CB_FE_RESET low (normal operation, boot default)

Built:    2026-07-23 from adc_4lane_framed/ (top_4lane_framed.v)
Verified: fe-on reproduces the golden midscale PASS (all 8 channels,
          stddev 7.0-8.7); fe-off streams real data with framing clean
          (0 CRC / 0 seq / 0 lane_id on all lanes); streaming resumes
          cleanly after chip-reset and fe-pulse.
SHA1:     43c2f4dfaabac358bd0e2f2facb4221993a7f1bc

Flash:
  /opt/oss-cad-suite/bin/openFPGALoader -c dirtyJtag --fpga-part LFE5U-25F -f \
      golden_bitstreams/adc_4lane_cmd_KNOWN_GOOD.bit

Midscale check (test mode must be enabled first):
  cd adc_4lane_framed && ./board_cmd fe-on && ./lane_test 8

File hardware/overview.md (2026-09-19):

# Board and system overview

Use these views to recognize the supplied boards, locate the main components and open the corresponding design files. The collection contains chip-carrier and LDO/routing references; it does not yet contain a finalized full-4K FPGA board or complete assembly.

## Overall 3D assembly

Earlier stacked-headboard assembly concept with labeled regions

**[Open the 3D STL](assembly/stacked_headboard_original.stl)** · [Download STL](assembly/stacked_headboard_original.stl?raw=true) · [Assembly guide and source details](assembly/README.md)

The earlier model discussion identified **A** as four ASIC-carrier boards with two ASICs each, **B + C** as the routing PCB, and **D** as the FPGA PCB. This is the original supplied arrangement model, with provisional dimensions and no encoded physical units. It covers the headboard assembly; the downstream KR260 and PC are shown in the functional diagram below. Its original author is unverified.

## Where the boards fit

The [September 17 meeting](../docs/meetings/2026-09-17.md#system-and-responsibilities) records this functional path:

```mermaid
flowchart LR
    A[Recording chips] --> B[Routing board]
    B --> C[FPGA board]
    C --> D[KR260]
    D --> E[PC]
```

The chip carrier supports the recording chips and their connections. Routing brings chip signals toward the FPGA, which receives and organizes data for the downstream platform. The diagram shows the intended data path, not a mechanical stack or final connector map. The [interface, power and startup questions](../docs/meetings/2026-09-17.md#questions-to-resolve-in-the-next-review) remain part of the design work.

## Original assembled-board photograph

Original slide showing an assembled single-chip carrier and a close-up of its bond wires

Slide 2 of the [interface presentation](../sources/slides/Chip_FPGA_Interface.pptx) shows a single-chip carrier and the bond wires connecting the die to the board. This is a separate source example from the two-chip PCB-5 layout below. Open the [full slide PDF](../sources/slides/Chip_FPGA_Interface.pdf) for the original presentation context.

## ASIC carrier PCB-5

Overall 3D view rendered from the supplied two-chip ASIC-carrier board file

The supplied board outline is approximately **22 × 17 mm**, with **10 copper layers**. The front has two chip footprints, `U01_BCD1` and `U01_BCD2`, with surrounding capacitors. The back has the **80-contact J3 connector**.

| Front layout | Back layout |
|---|---|
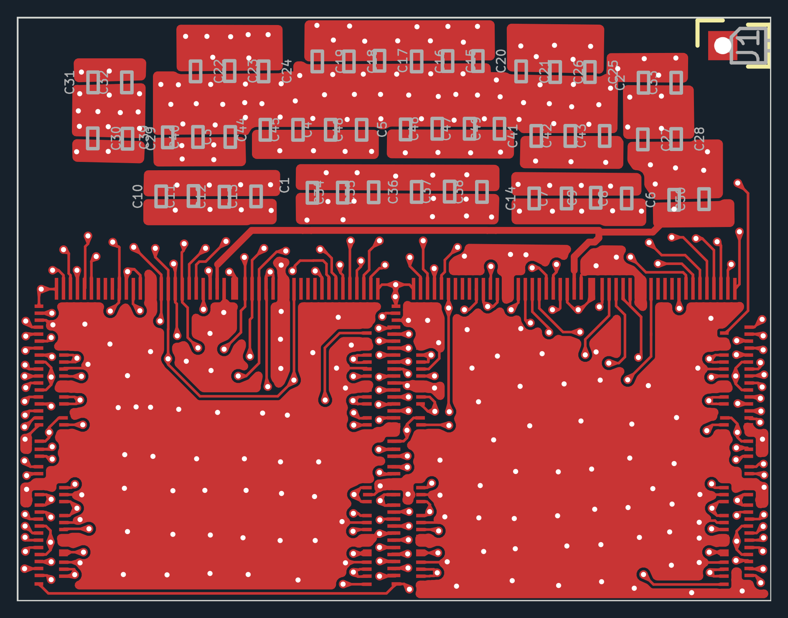
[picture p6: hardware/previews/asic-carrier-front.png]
ASIC-carrier front layout
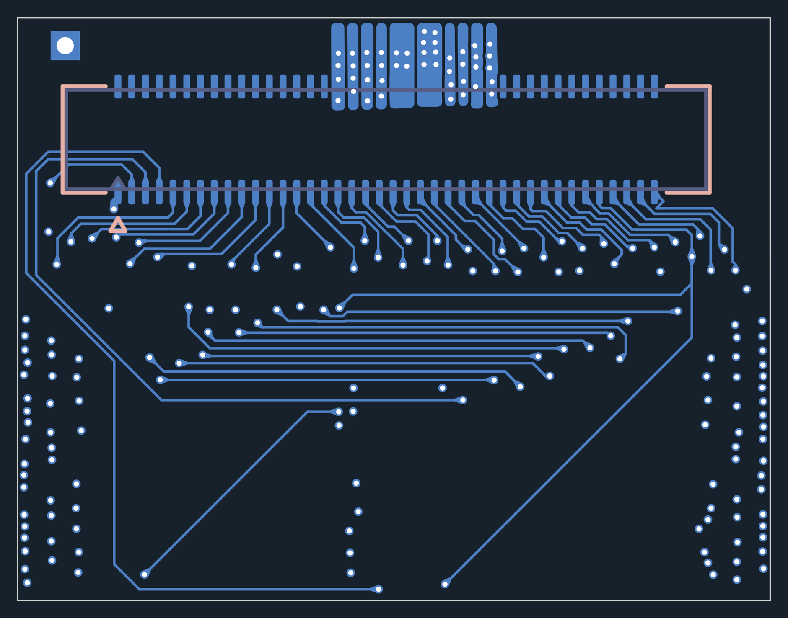
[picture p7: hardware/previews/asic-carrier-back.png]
ASIC-carrier back layout
|  |  |
| [Open scalable front view](previews/asic-carrier-front.svg) | [Open scalable back view](previews/asic-carrier-back.svg) |

Original files: [KiCad project](references/asic-carrier/PCB.kicad_pro) · [PCB](references/asic-carrier/PCB.kicad_pcb) · [schematic](references/asic-carrier/PCB.kicad_sch) · [pin-planning spreadsheet](references/asic-carrier/Pins.xlsx).

## LDO/routing reference

Overall 3D view rendered from the supplied LDO and routing board file

The supplied board outline is approximately **18.3 × 42.0 mm**, with **6 copper layers**. Nine regulator footprints, `U1`–`U9`, occupy the front-side regulator area. The narrower extension carries routing toward the lower connector region. The back includes two **50-contact board-to-board connectors**; the original file also preserves a separate 24-contact footprint with a duplicate `J1` reference.

| Front layout | Back layout |
|---|---|
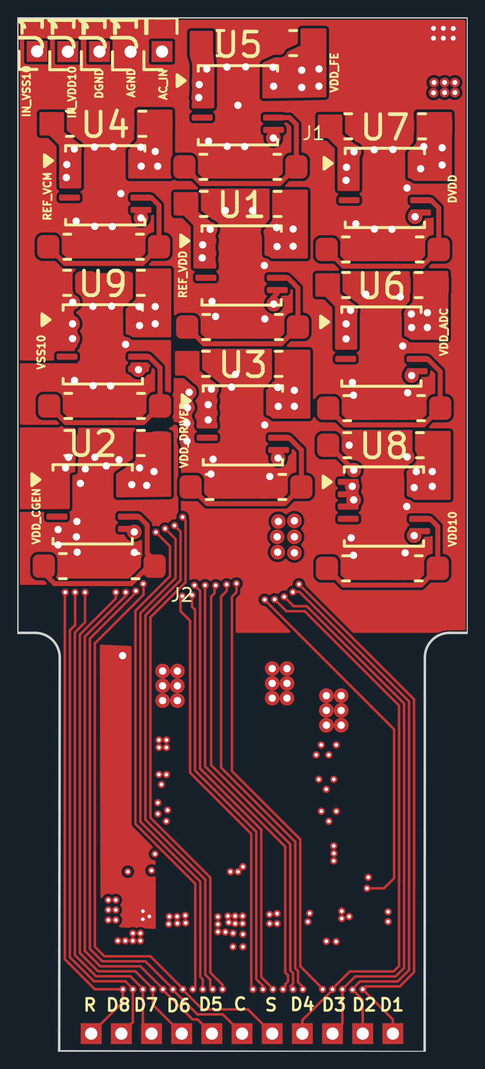
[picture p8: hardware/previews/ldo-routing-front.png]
LDO and routing board front layout
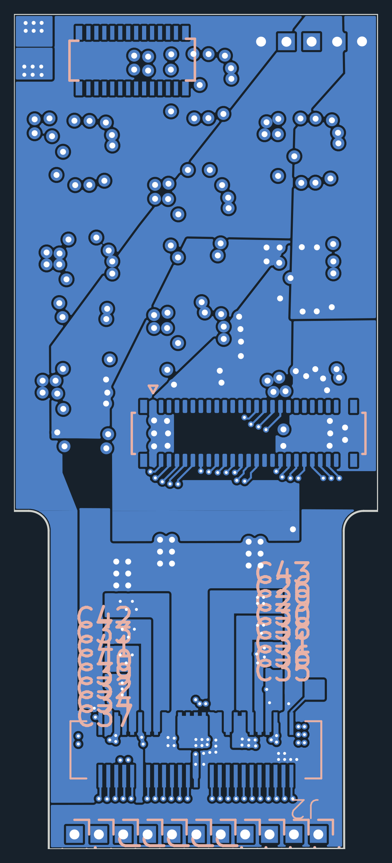
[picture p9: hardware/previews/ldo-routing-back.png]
LDO and routing board back layout
|  |  |
| [Open scalable front view](previews/ldo-routing-front.svg) | [Open scalable back view](previews/ldo-routing-back.svg) |

Original files: [KiCad project](references/ldo-routing/PCB.kicad_pro) · [PCB](references/ldo-routing/PCB.kicad_pcb) · [schematic](references/ldo-routing/PCB.kicad_sch) · [connector-footprint library](references/ldo-routing/LDO_Board.pretty/).

## Reading these views

The 3D images are CAD renders, not photographs of assembled hardware. Unavailable custom 3D models are absent; use the layout views and original CAD to identify all footprints. Back layouts are mirrored to show the board from its back side. Dimensions describe the supplied outlines and are not new-board size targets. The two references are **not a confirmed mating pair**: their 80- and 50-contact interfaces require reconciliation.

See the [hardware opening notes](README.md), [rendering notes](previews/README.md) and [source provenance](../sources/README.md) for file versions and reproduction details. The [team follow-up](../docs/meetings/2026-09-18-follow-up.md) and [program guide](../docs/software.md) connect these hardware references to the ongoing interface and software work.

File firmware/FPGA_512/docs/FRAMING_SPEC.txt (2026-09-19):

================================================================================
  SERIAL OUTPUT FRAMING SPECIFICATION
  8-Channel ADC → 4-Lane Serial Output (FPGA → UWB Chip)
  ECP5-5G Eval Board
================================================================================

OVERVIEW
--------
The FPGA receives 8 independent serial ADC bitstreams (D[1:8] via J32) and
merges them into 4 serial output lanes via an 8:4 TDM mux. Each lane carries
data from one channel pair. A framing structure is prepended and appended to
each block of 128 data words so that the downstream receiver (UWB chip) can:

  1. Lock to the correct word boundary (sync)
  2. Identify which lane (and therefore which channel pair) it is reading
  3. Know which position within the amplifier cycle it is at
  4. Detect transmission errors

LANE ASSIGNMENTS
----------------
  Lane 0  →  Channel 0 (even) + Channel 1 (odd)
  Lane 1  →  Channel 2 (even) + Channel 3 (odd)
  Lane 2  →  Channel 4 (even) + Channel 5 (odd)
  Lane 3  →  Channel 6 (even) + Channel 7 (odd)

Each lane is an independent 12-bit-wide serial stream.
Word width: 12 bits (matching the ADC resolution).

FRAME STRUCTURE  (per lane, per amplifier cycle)
-------------------------------------------------

  +----------------+----------------+----------------+-----...-----+----------+
  |  SYNC WORD     |  LANE ID       |  CYCLE COUNT   |  DATA × 128 |  CRC-12  |
  |  12 bits       |  12 bits       |  12 bits       |  1536 bits  |  12 bits |
  +----------------+----------------+----------------+-----...-----+----------+
   Word 0           Word 1           Word 2           Words 3–130   Word 131

Total frame length: 132 words × 12 bits = 1584 bits per lane per cycle.

FIELD DEFINITIONS
-----------------

[Word 0]  SYNC WORD  (12 bits)
  Unique per lane. Chosen for DC balance (6 ones, 6 zeros) and low
  autocorrelation with adjacent lane sync words to prevent cross-lane
  false lock.

    Lane 0:  12'b1010_0011_0101  (0xA35)
    Lane 1:  12'b1011_0100_0110  (0xB46)
    Lane 2:  12'b1100_0101_0111  (0xC57)
    Lane 3:  12'b1101_0110_1000  (0xD68)

  The receiver hunts for this exact 12-bit pattern to establish word lock.
  Lock is not declared until SYNC, LANE_ID, and CYCLE_CNT are all
  consistent across two consecutive frames.

[Word 1]  LANE ID  (12 bits)
  Encodes the lane number and an upstream drop count, with a redundancy
  check.

    Bits [11:6]  =  hi[5:0]  =  { drop_count[3:0], lane_number[1:0] }
    Bits  [5:0]  =  bitwise complement of hi[5:0]

  drop_count reports the number of samples per channel dropped upstream
  (sample-FIFO overflow during a downstream stall) since this lane's
  PREVIOUS frame, saturating at 15. Even and odd channels always drop
  together, so one count covers both. Drops are therefore never silent:
  a frame following any loss carries a non-zero drop_count.

  With drop_count == 0 the word is bit-identical to the legacy encoding
  (lane number zero-extended to 6 bits + complement), so decoders that
  match the constant word exactly remain correct in normal operation and
  flag a header error precisely when drops occur.

  Example — Lane 2, no drops:
    hi          = 6'b000010
    Bits  [5:0] = 6'b111101
    Combined:    12'b000010_111101

  Example — Lane 1, 3 samples/channel dropped:
    hi          = 6'b001101   (drop_count = 3, lane = 1)
    Bits  [5:0] = 6'b110010
    Combined:    12'b001101_110010

  The receiver accepts the field only if bits[5:0] == ~bits[11:6] and
  hi[1:0] matches the lane implied by the sync word. A mismatch flags a
  header error for this frame. The CRC covers the word as transmitted,
  including the drop count.

  Since channels within a lane alternate (even/odd), the receiver derives
  the specific channel numbers as:
    Channel even = lane_number × 2
    Channel odd  = lane_number × 2 + 1

[Word 2]  CYCLE COUNT  (12 bits)
  A 12-bit rolling counter (0–4095, wraps) incremented once per frame per
  lane. All four lanes increment their counters in lockstep.

  The receiver uses this to:
    - Confirm sequential frames are being received (no drops)
    - Determine position within the amplifier cycle
    - Re-synchronize after a gap (knows exactly where in the scan it is)

[Words 3–130]  DATA BLOCK  (128 × 12-bit words = 1536 bits)
  Contains 64 amplifier steps × 2 sub-channels (even + odd), interleaved:

    Word 3   →  Channel EVEN,  Amplifier 0
    Word 4   →  Channel ODD,   Amplifier 0
    Word 5   →  Channel EVEN,  Amplifier 1
    Word 6   →  Channel ODD,   Amplifier 1
    ...
    Word 129 →  Channel EVEN,  Amplifier 63
    Word 130 →  Channel ODD,   Amplifier 63

  Word position within the data block implicitly encodes (channel, amplifier):
    amplifier  = (word_index - 3) / 2
    is_odd_ch  = (word_index - 3) % 2

[Word 131]  CRC-12  (12 bits)
  CRC-12 computed over all preceding frame words (Words 0–130):
  SYNC, LANE_ID, CYCLE_CNT, and the 128 data words.

  Polynomial: 0x80F  (x^12 + x^11 + x^3 + x^2 + x + 1)
    — standard telecom CRC-12, matches ITU-T

  Error detection capability:
    - All single-bit errors: 100%
    - All double-bit errors: 100%
    - All triple-bit errors: 100%  (Hamming distance = 4)
    - All burst errors ≤ 12 bits: 100%
    - Longer random bursts: ~99.976% (undetected rate = 1/4096)

  A frame whose CRC does not match is discarded. The receiver re-locks on
  the next valid SYNC and uses CYCLE_CNT to determine how many frames were
  lost.

RECEIVER LOCK SEQUENCE
-----------------------
  1. Scan incoming 12-bit words for a known SYNC pattern (0xA35 / 0xB46 /
     0xC57 / 0xD68).
  2. On candidate SYNC match, check Word+1 for valid LANE_ID complement.
  3. Record CYCLE_CNT from Word+2.
  4. Verify CRC-12 at Word+131.
  5. On next frame, confirm SYNC reappears at Word+132, LANE_ID carries the
     same lane number (drop_count bits may differ), and CYCLE_CNT
     incremented by 1.
  6. Lock declared. Begin decoding data block using word-position mapping.

  False lock probability (all three header fields consistent by chance):
    P ≈ (1/4096) × (1/64) × (1/4096)  ≈  9 × 10⁻¹⁰  (effectively zero)

PHYSICAL OUTPUT  (J40, Bank 0, 3.3 V)
--------------------------------------
  Pin 1  (K2)   la_clk      — 32 MHz decode clock (passthrough of j33_clk32mhz)
  Pin 2         GND         — logic analyzer / receiver ground reference
  Pin 3  (A15)  la_data[0]  — Lane 0 serial stream  (channels 0 & 1)
  Pin 4  (F1)   la_data[1]  — Lane 1 serial stream  (channels 2 & 3)
  Pin 5  (H2)   la_data[2]  — Lane 2 serial stream  (channels 4 & 5)
  Pin 6  (G1)   la_data[3]  — Lane 3 serial stream  (channels 6 & 7)

  Data is clocked out MSB-first, one 12-bit word per 12 clock cycles.
  Data launches on the RISING edge of la_clk — receiver samples on the FALLING edge.

TIMING
------
  Serial clock:  32 MHz  (j33_clk32mhz, the device's own transmit clock)
  Bits per frame: 1584 bits per lane
  Frame rate:    32 MHz / 1584 ≈ 20.2 kHz
  Latency:       One frame (132 words) from rx_process_mux output to
                 first serial bit at J40

IMPLEMENTATION STATUS
---------------------
  [DONE]   rx_process_mux — 8-channel deserializer + 8:4 TDM mux
  [DONE]   top.v          — clock domains, reset sync, LA output ports
  [DONE]   clock.lpf      — pin constraints for J32, J33, J40
  [TODO]   Serializer module — takes out_word[0:3] + out_valid + out_chsel,
                               inserts framing, outputs 4 serial streams
  [TODO]   Replace la_data = out_valid (current placeholder) with
           actual serialized lane data
  [TODO]   Update sync words in rx_process_mux from shared 0xCAF/0xEF0/0x0D5
           to per-lane values 0xA35 / 0xB46 / 0xC57 / 0xD68

================================================================================

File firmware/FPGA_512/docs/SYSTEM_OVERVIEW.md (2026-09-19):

# FPGA System Overview — 8-Channel ADC Serial Receiver

This document describes the complete data path from ADC serial input through the FPGA to
serialized output. It is intended to give a new reader a full understanding of what the
system does at every stage.

---

## Hardware Context

- **FPGA**: LFE5U-25F-7BG256I (Lattice ECP5, 25k LUTs, BGA-256 package)
- **Clock**: 12 MHz from FTDI (eval board) or 16 MHz oscillator (custom board) via A7
- **ADC board**: Connected via CN1 board-to-board connector, supplies 8 differential
  serial channels and a 32 MHz decode clock
- **Output**: 4 serial lanes to a downstream receiver (logic analyzer / UWB chip)

---

## Stage 0 — ADC Serial Input Protocol

The ADC board drives 8 independent single-bit serial lines (`data_in[7:0]`) plus a
group-boundary pulse (`next_amps_in[7:0]`) per channel. The decode clock is 32 MHz
(`j33_clk32mhz`), giving a bit period of ~31.25 ns.

Each **64-cycle group** carries samples from 4 ADC sub-channels:

```
Cycle   0 .. 12   — 13 leading zeros       (ZERO_CYCLES = 13)
Cycle  13 .. 60   — 48 data bits           (4 ADCs × 12 bits, bit-interleaved)
Cycle  61 .. 63   — 3 trailing zeros       (ignored)
```

**Bit interleaving** within the data phase (cycles 13–60):

| Cycle | which_adc = (cyc-13) % 4 | which_bit = (cyc-13) / 4 |
|---|---|---|
|  13 | ADC 0 | bit 0  (LSB) |
|  14 | ADC 1 | bit 0 |
|  15 | ADC 2 | bit 0 |
|  16 | ADC 3 | bit 0 |
|  17 | ADC 0 | bit 1 |
| ... | ... | ... |
|  57 | ADC 0 | bit 11 (MSB) |
|  58 | ADC 1 | bit 11 |
|  59 | ADC 2 | bit 11 |
|  60 | ADC 3 | bit 11 |

Bits arrive **LSB-first**. The FPGA uses a right-shift accumulator so the word
is naturally assembled: after 12 shifts, `sr[0]` = bit 0 (LSB), `sr[11]` = bit 11 (MSB).

The `next_amps_in` pulse resets the 6-bit cycle counter at the start of each new group,
keeping the FPGA in sync with the ADC board.

---

## Stage 1 — Bit Deserializer (rx_process_mux, Stage 1)

**Module**: `rx_process_mux` in `fpga/UWB_Serial_Handler.v`

For each of the 8 serial channels independently:

1. A 6-bit counter (`cyc_in_group[ch]`) tracks position within the 64-cycle group,
   reset by `next_amps_in`.

2. Four 12-bit shift registers (`sr0`–`sr3`, one per interleaved ADC) accumulate bits:
   ```
   sr[which_adc][ch] <= {data_in[ch], sr[which_adc][ch][11:1]};
   ```
   New bits shift in from the MSB end, so the last shift produces the complete
   12-bit ADC word naturally.

3. A push fires when `which_bit == 11` (last bit of the 12-bit word) and the channel
   is in the data phase. This deposits the completed word into the per-channel **RX FIFO**
   (depth 16, width 12). Four pushes happen per group, one per ADC sub-channel (cycles 57–60).

Each of the 8 channels has its own RX FIFO, giving 8 independent word-rate queues.

---

## Stage 2 — RX FIFO → TX FIFO Passthrough (rx_process_mux, Stage 2)

Each channel drains its RX FIFO directly into a corresponding **TX FIFO** (also depth 16,
width 12):

```
rx_fifo_ren[ch]   = !rx_fifo_empty[ch] && !tx_fifo_full[ch];
tx_fifo_wen[ch]   = rx_fifo_ren[ch];
tx_fifo_wdata[ch] = rx_fifo_rdata[ch];
```

This stage is intentionally minimal — no data transformation occurs. Framing headers
(SYNC, LANE_ID, CYCLE_CNT, CRC-12) are inserted downstream by the `lane_framer` modules.
The two-FIFO buffer absorbs timing jitter between the ADC bit clock domain and the
downstream word-rate consumer.

---

## Stage 3 — 8:4 TDM Mux (rx_process_mux, Stage 3)

The 8 TX FIFOs feed a word-level **time-division multiplexer** that produces 4 output
lanes. Each lane carries data from one channel pair:

| Lane | Even channel | Odd channel |
|---|---|---|
|  0 | Channel 0 | Channel 1 |
|  1 | Channel 2 | Channel 3 |
|  2 | Channel 4 | Channel 5 |
|  3 | Channel 6 | Channel 7 |

Each lane has a 1-bit selector (`mux_sel[lane]`) that alternates between even and odd
channel priority. Each clock cycle, if the preferred channel has data the lane outputs it
and toggles `mux_sel`; if not, it tries the other channel (without toggling). If neither
has data, `out_valid[lane]` goes low for that cycle.

Outputs per clock:
- `out_valid[3:0]` — one bit per lane, high when a valid word is on that lane
- `out_word[47:0]` — packed 12-bit words: bits `[0+:12]`=lane0, `[12+:12]`=lane1, etc.
- `out_chsel[3:0]` — 0 = even channel served, 1 = odd channel served

---

## Stage 4 — Frame Assembly and Serialization (lane_framer)

**Module**: `lane_framer` in `fpga/UWB_Serial_Handler.v`
One instance per lane, parameterized with a unique `SYNC_WORD` and `LANE_NUM`.

### State machine: COLLECT → EMIT

**COLLECT**: Accepts incoming 12-bit words one at a time. Stores them in a 128-word data
buffer (`dbuf`) and accumulates a running CRC-12. When 128 words have been collected,
transitions immediately to EMIT. Any words arriving during EMIT are dropped.

**EMIT**: Serializes a complete 132-word frame MSB-first at 1 bit per clock (1584 clock
cycles total), then returns to COLLECT for the next frame.

### Frame Structure

```
Word   0       SYNC_WORD   12 bits  — unique per-lane sync pattern
Word   1       LANE_ID     12 bits  — lane number with complement check
Word   2       CYCLE_CNT   12 bits  — rolling frame counter (0–4095, wraps)
Words  3–130   DATA        128 × 12 bits = 1536 bits
Word 131       CRC-12      12 bits  — integrity check over words 3–130 only
─────────────────────────────────────
Total: 132 words × 12 bits = 1584 bits per frame
```

### Field Details

**SYNC_WORD** — DC-balanced (6 ones, 6 zeros), unique per lane:

| Lane | Hex | Binary |
|---|---|---|
|  0 | 0xA35 | 1010_0011_0101  |
|  1 | 0xB46 | 1011_0100_0110  |
|  2 | 0xC57 | 1100_0101_0111  |
|  3 | 0xD68 | 1101_0110_1000  |

**LANE_ID** — encodes lane number with a redundancy check:
```
bits[11:6] = {4'b0000, LANE_NUM}    (zero-extended lane index)
bits[5:0]  = ~bits[11:6]            (bitwise complement)
```
The receiver verifies `bits[5:0] == ~bits[11:6]`; a mismatch flags a header error.

**CYCLE_CNT** — 12-bit counter incremented once per frame. The receiver uses this to
detect dropped frames and determine position within the amplifier scan cycle.

**DATA block** (words 3–130) — 64 amplifier steps × 2 channels per lane, interleaved:
```
Word  3  → even channel, amplifier step 0
Word  4  → odd  channel, amplifier step 0
Word  5  → even channel, amplifier step 1
...
Word 129 → even channel, amplifier step 63
Word 130 → odd  channel, amplifier step 63
```

**CRC-12** — ITU-T CRC-12 computed MSB-first over the 128 data words only:
- Polynomial: `0x80F` (x¹² + x¹¹ + x³ + x² + x + 1)
- Seed: `0x000`
- Detects all 1-, 2-, 3-bit errors and all burst errors ≤ 12 bits (100% coverage)

---

## Physical Output

Data exits the FPGA as 4 independent serial bit streams:

| Signal | FPGA Pin | Description |
|---|---|---|
| `la_clk` | K2 | 32 MHz clock (passthrough of ADC decode clock) |
| `la_data[0]`| A15 | Lane 0 serial stream (channels 0 & 1) |
| `la_data[1]`| F1 | Lane 1 serial stream (channels 2 & 3) |
| `la_data[2]`| H2 | Lane 2 serial stream (channels 4 & 5) |
| `la_data[3]`| G1 | Lane 3 serial stream (channels 6 & 7) |

- Data launches on the **rising** edge of `la_clk`
- Receiver samples on the **falling** edge
- Bit order: **MSB first**

---

## Timing Summary

| Parameter | Value |
|---|---|
| ADC bit clock | ~21.3 MHz (32 MHz / 1.5, from ADC board group structure) |
| Decode clock | 32 MHz (`j33_clk32mhz`) |
| Bits per group | 64 cycles (13 zeros + 48 data + 3 trailing) |
| ADC words per group | 4 (one per interleaved sub-channel) |
| Frame size | 1584 bits (132 words × 12 bits) |
| Frame rate | 32 MHz / 1584 ≈ **20.2 kHz** |
| Latency | One frame (128 words collected before first bit emitted) |

---

## Receiver Lock Sequence

A downstream receiver locks to the stream as follows:

1. Scan incoming 12-bit words for a known SYNC pattern (0xA35, 0xB46, 0xC57, or 0xD68)
2. On a candidate match, verify Word+1 is a valid LANE_ID (complement check)
3. Record CYCLE_CNT from Word+2
4. Verify CRC-12 at Word+131
5. On the next frame, confirm SYNC reappears at Word+132, LANE_ID is unchanged,
   and CYCLE_CNT incremented by exactly 1
6. Lock declared — begin decoding the data block using word-position mapping

False lock probability ≈ 9 × 10⁻¹⁰ (effectively zero).

---

## Source Files

| File | Contents |
|---|---|
| `fpga/UWB_Serial_Handler.v` | `rx_process_mux`, `lane_framer`, `sync_fifo` |
| `fpga/top.v` | Top-level: clock, reset, I/O connections |
| `fpga/clock.lpf` | Pin constraints (J32 ADC in, J33 control, J40 output) |
| `docs/FRAMING_SPEC.txt` | Detailed frame field specification |

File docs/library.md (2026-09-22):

# Project files and documents

The original files are stored in this repository. Use the editable formats for further work and the PDFs or searchable notes for a quick review.

## Team workflow and editable design

- [Team start page](team/README.md), [contribution guide](../CONTRIBUTING.md), [owners and open work](team/owners-and-work.md).
- [FPGA working draft](../hardware/fpga-board/README.md): complete editable KiCad project and local libraries; not for manufacture.
- [Initial FPGA import evidence](../sources/fpga-draft-2026-09-21/README.md): provenance, original hashes and dated check reports.

## ASIC/interface slides

- [Original 28-slide PowerPoint](../sources/slides/Chip_FPGA_Interface.pptx)
- [Existing PDF representation](../sources/slides/Chip_FPGA_Interface.pdf)
- [Searchable slide text](slides/asic-interface-text.md) and [selected slide previews](../sources/slides/previews/)

Use the original slide diagrams for timing relationships that text extraction cannot preserve. The PDF, extracted text and PNGs are representations of the same deck.

## Team meeting records

- September 17: [searchable notes](meetings/2026-09-17.md), [Word](../sources/meetings/2026-09-17-notes.docx), [PDF](../sources/meetings/2026-09-17-notes.pdf).
- [Team follow-up received September 18](meetings/2026-09-18-follow-up.md): workstream assignments, development sequence, voltage/clock clarification and unresolved behavior.

These records summarize team discussions. The September 17 [questions for the next review](meetings/2026-09-17.md#questions-to-resolve-in-the-next-review) retain their dated context; they are not a current approved specification.

## Supplied hardware references

The earlier [overall 3D assembly](../hardware/assembly/README.md) includes the original [STL](../hardware/assembly/stacked_headboard_original.stl) and its labeled preview, showing the ASIC-carrier stack, routing section and FPGA-board arrangement. Model dimensions are provisional; source authorship is unverified.

The **[visual hardware overview](../hardware/overview.md)** brings together the system diagram, original assembly photograph, overall board renders and front/back layouts. [Downloadable PNG/SVG views](../hardware/previews/README.md) accompany the editable originals below.

| Reference | Original files | Opening notes |
|---|---|---|
| ASIC carrier PCB-5 | [KiCad project](../hardware/references/asic-carrier/PCB.kicad_pro), [schematic](../hardware/references/asic-carrier/PCB.kicad_sch), [PCB](../hardware/references/asic-carrier/PCB.kicad_pcb), [pin spreadsheet](../hardware/references/asic-carrier/Pins.xlsx) | [Carrier notes](../hardware/README.md#asic-carrier-pcb-5) |
| Older LDO/routing design | [KiCad project](../hardware/references/ldo-routing/PCB.kicad_pro), [schematic](../hardware/references/ldo-routing/PCB.kicad_sch), [PCB](../hardware/references/ldo-routing/PCB.kicad_pcb), [footprint library](../hardware/references/ldo-routing/LDO_Board.pretty/) | [LDO/routing notes](../hardware/README.md#ldorouting-reference) |

These are supplied examples. Their presence does not establish final mating compatibility, an approved new-board BOM or fabrication readiness.

## Previous acquisition code

- [Included FPGA_512 source and revision](../firmware/README.md)
- [Original project README](../firmware/FPGA_512/README.md)
- [FPGA top-level Verilog](../firmware/FPGA_512/fpga/top.v) and [FT600 host test in C](../firmware/FPGA_512/ft600_test/test_d3xx.c)
- [Original-program and run guide](software.md)
- [Upstream repository register](../references/README.md)

The source files are included at a pinned upstream revision for repeatable reading and use. This is the earlier ECP5/FT600 project; it does not establish compatibility with the proposed Artix-7 path or complete 4K operation. The separately labeled FPGA working draft is now included for team development; it does not change the status of this historical firmware.

[Source provenance and checksums](../sources/README.md) describe what is original, what is a faithful representation and the one library-path adaptation.

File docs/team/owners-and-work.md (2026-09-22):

# Owners and open work

Updated for the initial team handoff on 2026-09-21. Responsibilities below are roles to assign, not confirmed personal assignments. Record a GitHub username once the person accepts ownership.

| Workstream | Working source | Owner / reviewer | Next step |
|---|---|---|---|
| FPGA schematic and layout | [Working draft](../../hardware/fpga-board/README.md) | TBD / TBD | Review the baseline; claim exclusive board editing in an issue |
| ASIC carrier | [Preserved reference](../../hardware/references/asic-carrier/PCB.kicad_pro) | TBD / TBD | Confirm the authoritative editable project before creating a working copy |
| Routing and power board | [Historical reference](../../hardware/references/ldo-routing/PCB.kicad_pro) | TBD / TBD | Confirm topology and baseline; do not assume this example mates with the carrier |
| Receiver / KR260 interface | [Recorded context](../meetings/2026-09-18-follow-up.md) | TBD / TBD | Specify actual receiver hardware and electrical link |
| FPGA firmware / host software | [Earlier ECP5/FT600 code](../../firmware/README.md) | TBD / TBD | Identify reusable pieces and new Artix-7 work |

## Decisions blocking electrical completion

| Decision | Required owners | Evidence to close it |
|---|---|---|
| Carrier → routing → FPGA connector map | Carrier + routing + FPGA | Matching pin tables, directions, IO voltages, grounds, mating parts and mechanics |
| ASIC timing and startup | ASIC + FPGA | Reviewed timing diagrams, voltage limits and reset/startup behavior |
| Rail currents, compensation and sequencing | Power + FPGA | Reviewed power budget, regulator calculations and startup requirements |
| RAM part/controller and bank assignments | FPGA + firmware | Chosen part, ballout, VCCO/VREF/VTT and timing constraints |
| FPGA oscillator and clock architecture | FPGA + receiver | Frequency, jitter, voltage and acquisition/link clock plan |
| Custom micro-HDMI link and receiver | FPGA + receiver | Protocol, signaling, pin map, termination/protection and end-to-end receiver path |
| BGA escape and stackup | Layout + fabricator | Approved layers, dielectric, impedance and trace/via/assembly capabilities |
| FPGA unused/analog/transceiver/battery pins | FPGA | Manufacturer-grounded used/unused pin treatment and bank supplies |

The micro-HDMI connector choice does not specify HDMI signaling or direct KR260 compatibility. The FPGA device direction is XC7A200T; package/speed/temperature fields in the draft still require procurement qualification.

## Layout ownership record

Before starting layout, open a PCB task and record:

```text
Board:
Owner GitHub username:
Reviewer GitHub username:
Branch and starting commit:
Files / schematic sheets in scope:
Interface changes:
Handoff commit and remaining work:
Next owner:
```

Use one open ownership task per board and close or hand it off explicitly. A separate branch alone does not reserve the layout. Until an owner accepts the task, layout ownership remains unassigned.

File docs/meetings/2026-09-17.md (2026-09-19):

# September 17, 2026 meeting record

> Dated team meeting record. Device and interface statements below describe that discussion, not a guarantee of the team's current implementation. See [the supplied team follow-up](2026-09-18-follow-up.md) for later reported context.

Readable summary of the final [Word notes](../../sources/meetings/2026-09-17-notes.docx); [PDF](../../sources/meetings/2026-09-17-notes.pdf). Wording is organized around the technical topics; participants and action owners are retained. The original documents are unchanged. This is a meeting summary, not a verbatim transcript.

September 17, 2026  |  BioScience Research Collaborative  |  29 min 36 sec

Participants identified: Gerald, Howard, and Zitong. David and an FPGA firmware collaborator were discussed as interface collaborators.

## Main outcome

Prioritize a compact FPGA board and a workable FPGA-to-KR260 interface for the eight-chip, approximately 4K-channel recording system. Howard and Zitong should work together to identify everything needed for power-up, configuration, control and data transfer before finalizing the hardware. The FPGA-to-KR260 connection was the main unresolved interface.

## System and responsibilities

Recording chips → routing board → FPGA board → KR260 → PC

Chip and routing side. The routing board brings chip signals to the FPGA board. Two detachable board-to-board connectors were discussed. The chip pin locations and reference designs are inputs to the mating connections, which Howard and Zitong need to agree on.

FPGA side. Howard’s main responsibility is the FPGA board. It receives and organizes chip data and forwards it over fewer signal lines. The two board designers should collaborate, especially on the less familiar FPGA support circuitry.

Downstream side. KR260 was named as the downstream platform and called the “MCU” in the meeting. Coordinate its interface with David and the FPGA firmware collaborator. The intended control path comes from this downstream platform.

## Agreed direction

Design tool. Use KiCad for the PCB work. Check version compatibility when opening the shared files.

FPGA baseline. Artix-7 XC7A35T was the referenced FPGA discussed in this meeting. Confirm the complete ordering code and package from that reference before finalizing the design.

Size and usability. Minimize the board and support components, with a preference for a compact rather than elongated shape. Users should be able to power it on without manually reprogramming it each time.

Power and fabrication. Place FPGA power circuitry on the FPGA board. Recording-chip power placement remains under review. JLC was the preferred fabrication/assembly option.

## Technical discussion and open questions

Chip-to-FPGA pin count. About 88 data signals and roughly 100–110 total signals including programming/control were discussed. These are estimates, not an approved connector pinout; the transcript contains inconsistent later numbers. The authoritative chip pin map must settle the count and direction of each signal.

FPGA-to-KR260 link. USB-C was favored as a possible compact connector, with micro-HDMI as an alternative. Selection depends on the usable cable conductors and interface needs. No USB or HDMI signaling protocol was agreed. A downstream adapter board was also proposed.

Data aggregation. Combining chip outputs into two to four data lines was a design question, not a demonstrated capability or finalized lane count. The interface also needs to accommodate control and programming. The team must determine what the hardware and firmware can support together.

Configuration and storage. Local memory that loads the FPGA at startup was discussed as a way to avoid manual reprogramming after power-off. Memory selection, loading method, required pins and the downstream platform’s role remain open. Configuration storage and recording-data buffering need separate requirements.

Power and board layout. Required FPGA supplies and support components need a datasheet/reference-design review. Placement of recording-chip LDOs may change to reduce size. The dimensions quoted for the existing reference were approximately 23 × 23 for the FPGA and 60 × 50 for the board; these are not new-board targets. Final dimensions and layer count were not selected.

Future functions. High-pass and low-pass filtering were mentioned as possible future requirements from Chong. They were not committed as immediate deliverables.

## Questions to resolve in the next review

1. What complete FPGA part number and package will the design use, and what is the minimum circuitry needed to power, start, configure and operate it?

2. What is the exact chip-to-FPGA signal list, including data, timing, control and programming signals and their directions?

3. What data rate must the FPGA-to-KR260 link carry, and how many data and control lines does the chosen implementation require?

4. Which connector, cable and signaling scheme can both the FPGA firmware and KR260 support?

5. How will initial programming, automatic startup and later configuration updates work for the end user?

6. Where will recording-chip power regulation sit, and what dimensions and PCB layer count are practical?

## Action items

Prepare the FPGA requirements and interface questions for the next discussion. Apart from that next-review expectation, individual completion dates were not set.

Research the minimum FPGA support design

Owner: Howard with Zitong

Bring a component/function list covering power, startup, configuration, programming, input/output and data transfer, with unresolved choices clearly marked.

Provide authoritative chip information

Owner: Gerald

Supply chip pin locations. Chip-board and older routing/LDO-board examples were shared during the meeting; the older routing example needs adaptation for eight chips.

Review references and align board interfaces

Owner: Howard and Zitong

Open the shared designs in a compatible KiCad version, reconcile the pin list, and agree on connector placement and mating connections.

Develop the FPGA-to-KR260 interface

Owner: Howard and Zitong with the FPGA firmware collaborator and David

Review available pins, data aggregation, control/programming needs and downstream support together, with the ASIC designer involved as needed.

Finalize recurring-meeting logistics

Owner: Meeting organizer to confirm

Confirm the invitation and room for Wednesday at 4:00 PM. Clarify whether a Zoom link is needed.

## Next meeting and other logistics

The group agreed on a recurring Wednesday meeting at 4:00 PM, after considering earlier times. In-person participation was planned. The room, invitation owner and any Zoom arrangements still need confirmation. The next regular Wednesday is September 23, 2026, subject to the calendar invitation.

A possible ninth-floor desk was discussed, but availability and assignment were not confirmed.

## Recording reference

BioScience Research Collaborative.m4a — recorded September 17, 2026 at approximately 1:19 PM Central; duration 29 minutes 36 seconds. The FPGA firmware collaborator’s name needs confirmation.

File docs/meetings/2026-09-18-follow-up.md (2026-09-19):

# Team follow-up received September 18, 2026

This is a technical summary of supplied team messages, not an independent design study. The pasted messages included times of day but no source dates or permalinks; September 18 is the **received date**, not a verified date for each message. Raw private chat is not republished.

## Reported responsibilities

| Workstream | Collaborator named in the team discussion |
|---|---|
| ASIC / 1,024-channel two-chip carrier designs | Gerald |
| Routing and power-management PCB | Zitong |
| FPGA PCB | Howard |
| FPGA programming | Jiaao |
| Downstream / “MCU” programming | David |

These are the reported assignments, not claims that the work is complete.

## Development sequence discussed

The initial sequence was to establish an Artix-7 evaluation-board-to-laptop path with an FX3 USB 3.0 board, test the required aggregate rate using FPGA-generated data, design a compact custom board, then transfer and test the firmware with the complete setup. Requirements work could proceed alongside evaluation-board tests. These were proposed steps, not passed tests.

A later update describes the path as **ASIC boards → routing board → FPGA board → cable → downstream platform → SFP+ → PC**. The [September 17 meeting](2026-09-17.md) identifies KR260 as the downstream platform. These records do not provide a finalized connector, electrical interface or protocol.

## Reference voltage and ASIC clock

The supplied clarification states: **“The reference voltage is 1.5V and the clock should 32MHz.”**

Retain this as the nominal reference and intended ASIC clock. It does not specify all ASIC supply rails, complete input/output limits or the FPGA's physical oscillator frequency.

## Reported progress and unresolved behavior

The reported activities were evaluation-board handoff for FPGA programming, ASIC timing discussions, coordination between the routing and FPGA boards, and ongoing carrier-board development. The downstream workstream was to investigate high-rate reception and forwarding to the PC. These are reported activities, not demonstrated end-to-end results.

The supplied discussion also reports a control/software problem with recording immediately after stimulation while Trodes occupies the FPGA. Its resolution and the intended first-system stimulation behavior are not established in the supplied material.

For the original meeting's unresolved requirements, see [its questions for the next review](2026-09-17.md#questions-to-resolve-in-the-next-review). [Source provenance](../../sources/README.md) records the origin and limits of this summary. Separate personal device, connector, component and board-size proposals are outside this meeting record.

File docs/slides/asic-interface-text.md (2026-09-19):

# ASIC interface slides: searchable text

[Original PowerPoint](../../sources/slides/Chip_FPGA_Interface.pptx) · [Existing PDF render](../../sources/slides/Chip_FPGA_Interface.pdf)

28 slides. Text is extracted from each original slide and its matching PDF page. Image-only labels, equations, waveforms and graphical relationships may be absent or reordered: inspect the original slide/PDF for timing and pin interpretation. Slide number means the presentation page, not a new specification revision. The 4,096-channel system is the later eight-chip plan.

## Slide 1

### PowerPoint text

```text
1
ASIC Layout
7mm
8.1 mm
7mm
8.1 mm
512 Recording Pixels128/512 Stimulating

PGA BUFFERSAR ADCs
PGA BUFFERSAR ADCs
```

### PDF text

```text
RISE
1
ASIC Layout
7mm
8.1 mm
7mm
8.1 mm
512 Recording Pixels
128/512 Stimulating
PGA
BUFFER
SAR ADCs
PGA
BUFFER
SAR ADCs
```

## Slide 2

### PowerPoint text

```text
2
Bonding Map
Bonding recipe for the ASIC-board connection
```

### PDF text

```text
RISE
2
Bonding Map
• Bonding recipe for the ASIC-board connection

```

## Slide 3

### PowerPoint text

```text
3
Chip Specifications
Gain
Programmable 3bits: (110 – 700)
Raw data bandwidth: (0.3Hz – 10kHz)
Input Referred Noise: (4 – 5uVrms)
Sampling rate: (31.25kS/s)
Stimulator
128 channels: Compliance of +/-10V
Resolution: 1.5uA
Maximum Current: 22.5uA
```

### PDF text

```text
RISE
3
Chip Specifications
• Gain
• Programmable 3bits: (110 – 700)
• Raw data bandwidth: (0.3Hz – 10kHz)
• Input Referred Noise: (4 – 5uVrms)
• Sampling rate: (31.25kS/s)
• Stimulator
– 128 channels: Compliance of +/-10V
– Resolution: 1.5uA
– Maximum Current: 22.5uA
Parameter Value
Channels 512
Gain (V/V) 110–700
Bandwidth (Hz) 0.3–10k
Input-Referred Noise 4–5 µVrms
ADC Resolution 12-bit
Reset Time < 1.5 ms
Power / Channel <20 µW
Input Impedance 13 MΩ @ 1 kHz
Sampling Rate 31.25 kS/s per channel
Stimulator
Channels 128
Compliance Voltage ±10 V
Max Stimulation Current 22.5 µA
Stimulation Resolution 1.5 µA
Stimulation Frequency < 200 Hz
Temporal Resolution 31.25 µs
Stimulation Mode Arbitrary Monopolar / Bipolar
Charge Balancing < 10 mV residual
Process Node TSMC 180nm BCD
Supply Voltage 1.5 V
Die Area 8.1 × 7 mm
Interface Custom (SpikeGadgets)
Recording
Chip
Neural Recording Chip Specifications

```

## Slide 4

### PowerPoint text

```text
4
Chip Specifications
Gain
Programmable 3bits: (110 – 700)
Raw data bandwidth: (0.3Hz – 10kHz)
Input Referred Noise: (4 – 5uVrms)
Sampling rate: (31.25kS/s)
Stimulator
128 channels: Compliance of +/-10V
Resolution: 1.5uA
Maximum Current: 22.5uA
```

### PDF text

```text
RISE
4
Chip Specifications
• Gain
• Programmable 3bits: (110 – 700)
• Raw data bandwidth: (0.3Hz – 10kHz)
• Input Referred Noise: (4 – 5uVrms)
• Sampling rate: (31.25kS/s)
• Stimulator
• 128 channels: Compliance of +/-10V
• Resolution: 1.5uA
• Maximum Current: 22.5uA
Parameter Value
Channels 512
Gain (V/V) 110–700
Bandwidth (Hz) 0.3–10k
Input-Referred Noise 4–5 µVrms
ADC Resolution 12-bit
Reset Time < 1.5 ms
Power / Channel <20 µW
Input Impedance 13 MΩ @ 1 kHz
Sampling Rate 31.25 kS/s per channel
Stimulator
Channels 128
Compliance Voltage ±10 V
Max Stimulation Current 22.5 µA
Stimulation Resolution 1.5 µA
Stimulation Frequency < 200 Hz
Temporal Resolution 31.25 µs
Stimulation Mode Arbitrary Monopolar / Bipolar
Charge Balancing < 10 mV residual
Process Node TSMC 180nm BCD
Supply Voltage 1.5 V
Die Area 8.1 × 7 mm
Interface Custom (SpikeGadgets)
Recording
Chip
Neural Recording Chip Specifications

```

## Slide 5

### PowerPoint text

```text
5
3.2 mm
360µn

Recording and Stimulation
Modular concept
One module: 16 amplifiers + 4 stimulators
Arrange 32 copies to make it 512 recording + 128 stimulators
Programming interface programs the stimulators and the amplifiers
The ADCs are multiplexed to 8 data lines
```

### PDF text

```text
5
3.2 mm
360µn
Programming
Interface
8 × LNAs
8 × LNAs
4 × Stimulators
16 ×
Programmable
Gain Amplifiers
16 × ADC Drivers 12-bit ADC
Recording and Stimulation
• Modular concept
• One module: 16 amplifiers + 4 stimulators
• Arrange 32 copies to make it 512 recording +
128 stimulators
• Programming interface programs the
stimulators and the amplifiers
• The ADCs are multiplexed to 8 data lines
MUX
4-1
ADC 16 × Amp & 4 × Stim
ADC 16 × Amp & 4 × Stim
ADC 16 × Amp & 4 × Stim
ADC 16 × Amp & 4 × Stim
DATA<1>
MUX
4-1
ADC 16 × Amp & 4 × Stim
ADC 16 × Amp & 4 × Stim
ADC 16 × Amp & 4 × Stim
ADC 16 × Amp & 4 × Stim
DATA<2>
MUX
4-1
ADC 16 × Amp & 4 × Stim
ADC 16 × Amp & 4 × Stim
ADC 16 × Amp & 4 × Stim
ADC 16 × Amp & 4 × Stim
DATA<3>
MUX
4-1
ADC 16 × Amp & 4 × Stim
ADC 16 × Amp & 4 × Stim
ADC 16 × Amp & 4 × Stim
ADC 16 × Amp & 4 × Stim
DATA<4>
MUX
4-1
ADC16 × Amp & 4 × Stim
ADC16 × Amp & 4 × Stim
ADC16 × Amp & 4 × Stim
ADC16 × Amp & 4 × Stim
DATA<8>
MUX
4-1
ADC16 × Amp & 4 × Stim
ADC16 × Amp & 4 × Stim
ADC16 × Amp & 4 × Stim
ADC16 × Amp & 4 × Stim
DATA<7>
MUX
4-1
ADC16 × Amp & 4 × Stim
ADC16 × Amp & 4 × Stim
ADC16 × Amp & 4 × Stim
ADC16 × Amp & 4 × Stim
DATA<6>
MUX
4-1
ADC16 × Amp & 4 × Stim
ADC16 × Amp & 4 × Stim
ADC16 × Amp & 4 × Stim
ADC16 × Amp & 4 × Stim
DATA<5>
```

[Timing/specification preview](../../sources/slides/previews/slide-05.png)

## Slide 6

### PowerPoint text

```text
6
From Pixel Input to ADC Output
Gain: 100 – 700 (V/V)
Bandwidth: ~0.3 Hz to 10 kHz
IRN = 4 – 5  µVrms
Sampling Rate: 31.25 kS/s per channel
3.2 mm
360µn
IRN (Input-Referred Noise): ~4.2 µVrms

Recording Mode
```

### PDF text

```text
6
• From Pixel Input to ADC Output
• Gain: 100 – 700 (V/V)
• Bandwidth: ~0.3 Hz to 10 kHz
• IRN = 4 – 5  µVrms
• Sampling Rate: 31.25 kS/s per channel
3.2 mm
360µn
Programming
Interface
8 × LNAs
8 × LNAs
4 × Stimulators
16 ×
Programmable
Gain Amplifiers
16 × ADC Drivers 12-bit ADC
IRN (Input-Referred Noise): ~4.2 µVrms
Recording Mode
```

## Slide 7

### PowerPoint text

```text
7
Recording Mode
From Pixel Input to ADC Output
Gain: 100 – 700 (V/V)
Bandwidth: ~0.3 Hz to 10 kHz
IRN = 4 – 5  µVrms
Sampling Rate: 31.25 kS/s per channel
DC Power: ~17.24 µW / channel
Not including the external LDOs
3.2 mm
360µn

```

### PDF text

```text
7
Recording Mode
• From Pixel Input to ADC Output
• Gain: 100 – 700 (V/V)
• Bandwidth: ~0.3 Hz to 10 kHz
• IRN = 4 – 5  µVrms
• Sampling Rate: 31.25 kS/s per channel
• DC Power: ~17.24 µW / channel
• Not including the external LDOs
3.2 mm
360µn
Programming
Interface
8 × LNAs
8 × LNAs
4 × Stimulators
16 ×
Programmable
Gain Amplifiers
16 × ADC Drivers 12-bit ADC

```

[Timing/specification preview](../../sources/slides/previews/slide-07.png)

## Slide 8

### PowerPoint text

```text
8
Recording Mode

Integrated ASIC + Probe noise
µ = 6.5µVRMS and σ = 0.3µVRMS
```

### PDF text

```text
8
Recording Mode
• Integrated ASIC + Probe noise
• µ = 6.5µVRMS and σ = 0.3µVRMS
```

## Slide 9

### PowerPoint text

```text
9
Reading Mode – How?
Custom GUI
Recording on the top
Stimulation on the bottom

```

### PDF text

```text
RISE
9
Reading Mode – How?
• Custom GUI
– Recording on the top
– Stimulation on the bottom

```

## Slide 10

### PowerPoint text

```text
10
Reading Mode – How?
Custom GUI
Recording on the top
Stimulation on the bottom
Start recording
Sends a sequence to FPGA to trigger the recording

```

### PDF text

```text
RISE
10
Reading Mode – How?
• Custom GUI
– Recording on the top
– Stimulation on the bottom
• Start recording
– Sends a sequence to FPGA to
trigger the recording

```

## Slide 11

### PowerPoint text

```text
11
Reading Mode – How?
Custom GUI
Recording on the top
Stimulation on the bottom
Start recording
Sends a sequence to FPGA to trigger the recording
Reset amplifier
It sends a sequence to FPGA to trigger the reset the amplifiers

```

### PDF text

```text
RISE
11
Reading Mode – How?
• Custom GUI
– Recording on the top
– Stimulation on the bottom
• Start recording
– Sends a sequence to FPGA to
trigger the recording
• Reset amplifier
– It sends a sequence to FPGA to
trigger the reset the amplifiers

```

## Slide 12

### PowerPoint text

```text
12
Reading Mode – How?
Custom GUI
Recording on the top
Stimulation on the bottom
Start recording
Sends a sequence to FPGA to trigger the recording
Reset amplifier
It sends a sequence to FPGA to trigger the reset the amplifiers
Left and Right Gain
They control the gains of the two sides of the chip (they can be different if needed)
Gain will be programmed only if Program Gains is pressed

```

### PDF text

```text
RISE
12
Reading Mode – How?
• Custom GUI
– Recording on the top
– Stimulation on the bottom
• Start recording
– Sends a sequence to FPGA to
trigger the recording
• Reset amplifier
– It sends a sequence to FPGA to
trigger the reset the amplifiers
• Left and Right Gain
– They control the gains of the two
sides of the chip (they can be
different if needed)
– Gain will be programmed only if
Program Gains is pressed

```

## Slide 13

### PowerPoint text

```text
13
What happens in the background
Recording Related Pins
Chip_Reset: We use this pin to reset the chip to a known state
CLK32MHz_In: If we press start recording button, the FPGA sends this clock to the ASIC to start the recording
FE_RESET: If we press reset amplifier button, the FPGA resets the amplifiers we should see very silent channels
Amplifier Gain: Amplifier gain is set by a Serial Peripheral Interface (SPI will talk more about this later)

```

### PDF text

```text
RISE
13
What happens in the background
• Recording Related Pins
– Chip_Reset: We use this pin to reset the chip to a known state
– CLK32MHz_In: If we press start recording button, the FPGA sends this clock to the ASIC to start the recording
– FE_RESET: If we press reset amplifier button, the FPGA resets the amplifiers we should see very silent channels
– Amplifier Gain: Amplifier gain is set by a Serial Peripheral Interface (SPI will talk more about this later)

```

[Timing/specification preview](../../sources/slides/previews/slide-13.png)

## Slide 14

### PowerPoint text

```text
14
What happens in the background
Recording Related Pins
Chip_Reset: We use this pin to reset the chip to a known state
CLK32MHz_In: If we press start recording button, the FPGA sends this clock to the ASIC to start the recording
FE_RESET: If we press reset amplifier button, the FPGA resets the amplifiers we should see very silent channels
Amplifier Gain: Amplifier gain is set by a Serial Peripheral Interface (SPI will talk more about this later)
When recording starts: Chip will transmit these signals
CLK32MHz_Out: Used by FPGA to readout the correct data
Data<1:8>: Contains the recording data
Each data line contains the information of 4 ADC (time multiplexed)
One ADC  16amps, then 1 Data  64 amps.
Read: Used to let the FPGA know that a new amplifier’s data is being streamed
Sync: Used to let the FPGA know which amplifier’s data is being streamed

```

### PDF text

```text
RISE
14
What happens in the background
• Recording Related Pins
– Chip_Reset: We use this pin to reset the chip to a known state
– CLK32MHz_In: If we press start recording button, the FPGA sends this clock to the ASIC to start the recording
– FE_RESET: If we press reset amplifier button, the FPGA resets the amplifiers we should see very silent channels
– Amplifier Gain: Amplifier gain is set by a Serial Peripheral Interface (SPI will talk more about this later)
• When recording starts: Chip will transmit these signals
– CLK32MHz_Out: Used by FPGA to readout the correct data
– Data<1:8>: Contains the recording data
• Each data line contains the information of 4 ADC (time multiplexed)
• One ADC  16amps, then 1 Data  64 amps.
– Read: Used to let the FPGA know that a new amplifier’s data is being streamed
– Sync: Used to let the FPGA know which amplifier’s data is being streamed

```

[Timing/specification preview](../../sources/slides/previews/slide-14.png)

## Slide 15

### PowerPoint text

```text
15
Communication Protocol
1 Frame = 1024 clock cycles
Within each frame, there is one Sync and 16 Read
Sync, signals when the FPGA should start streaming the data  aligns the channel map
Read signals a new amplifier is being streamed
Within each Read period, DATA streams information about 4 amplifiers (from 4 different ADCs which share the same data line)
They all have the same location in a group of 16

```

### PDF text

```text
RISE
15
Communication Protocol
• 1 Frame = 1024 clock cycles
• Within each frame, there is one Sync and 16 Read
• Sync, signals when the FPGA should start streaming the data  aligns the channel map
• Read signals a new amplifier is being streamed
– Within each Read period, DATA streams information about 4 amplifiers (from 4 different ADCs which share
the same data line)
– They all have the same location in a group of 16

```

[Timing/specification preview](../../sources/slides/previews/slide-15.png)

## Slide 16

### PowerPoint text

```text
16
Communication Protocol
1 Frame = 1024 clock cycles
Within each frame, there is one Sync and 16 Read
Sync, signals when the FPGA should start streaming the data  aligns the channel map
Read signals a new amplifier is being streamed
Within each Read period, DATA streams information about 4 amplifiers (from 4 different ADCs which share the same data line)
They all have the same location in a group of 16

```

### PDF text

```text
RISE
16
Communication Protocol
• 1 Frame = 1024 clock cycles
• Within each frame, there is one Sync and 16 Read
• Sync, signals when the FPGA should start streaming the data  aligns the channel map
• Read signals a new amplifier is being streamed
– Within each Read period, DATA streams information about 4 amplifiers (from 4 different ADCs which share
the same data line)
– They all have the same location in a group of 16

```

[Timing/specification preview](../../sources/slides/previews/slide-16.png)

## Slide 17

### PowerPoint text

```text
17
Communication Protocol
1 Frame = 1024 clock cycles
Within each frame, there is one Sync and 16 Read
Sync, signals when the FPGA should start streaming the data  aligns the channel map
Read signals a new amplifier is being streamed
Within each Read period, DATA streams information about 4 amplifiers (from 4 different ADCs which share the same data line)
They all have the same location in a group of 16

```

### PDF text

```text
RISE
17
Communication Protocol
• 1 Frame = 1024 clock cycles
• Within each frame, there is one Sync and 16 Read
• Sync, signals when the FPGA should start streaming the data  aligns the channel map
• Read signals a new amplifier is being streamed
– Within each Read period, DATA streams information about 4 amplifiers (from 4 different ADCs which share
the same data line)
– They all have the same location in a group of 16

```

[Timing/specification preview](../../sources/slides/previews/slide-17.png)

## Slide 18

### PowerPoint text

```text
18
Stimulation Mode
Biphasic stimulation (monopolar/bipolar)
Fully programmable arbitrary waveform
±10V stimulation compliance
Passive charge balancing

```

### PDF text

```text
RISE
18
Stimulation Mode
• Biphasic stimulation (monopolar/bipolar)
• Fully programmable arbitrary waveform
• ±10V stimulation compliance
• Passive charge balancing

```

## Slide 19

### PowerPoint text

```text
19
Stimulation Mode - How
Up to ~22.5µA (4-bit control) with a resolution of ~1.5 µA

```

### PDF text

```text
RISE
19
Stimulation Mode - How
• Up to ~22.5µA (4-bit control) with a resolution of ~1.5 µA

```

## Slide 20

### PowerPoint text

```text
20
Stimulation Mode - How
There are 64 stimulator in each side,left and right

```

### PDF text

```text
RISE
20
Stimulation Mode - How
• There are 64 stimulator in each side,
left and right

```

## Slide 21

### PowerPoint text

```text
21
Stimulation Mode - How
There are 64 stimulator in each side,left and right
Select the stimulator
Fill the edge information based
Fill the anode and cathode information
Polarity
Stimulators can have different setting

```

### PDF text

```text
RISE
21
Stimulation Mode - How
• There are 64 stimulator in each side,
left and right
• Select the stimulator
– Fill the edge information based
– Fill the anode and cathode
information
– Polarity
• Stimulators can have different
setting

```

## Slide 22

### PowerPoint text

```text
22
Stimulation Mode - How
There are 64 stimulator in each side,left and right
Select the stimulator
Fill the edge information based
Fill the anode and cathode information
Polarity
Stimulators can have different setting

```

### PDF text

```text
RISE
22
Stimulation Mode - How
• There are 64 stimulator in each side,
left and right
• Select the stimulator
– Fill the edge information based
– Fill the anode and cathode
information
– Polarity
• Stimulators can have different
setting
```

## Slide 23

### PowerPoint text

```text
23
Stimulation Mode - How
There are 64 stimulator in each side,left and right
Select the stimulator
Fill the edge information based
Fill the anode and cathode information
Polarity
Stimulators can have different setting
Can program multiple of these stimulators at the same time

```

### PDF text

```text
RISE
23
Stimulation Mode - How
• There are 64 stimulator in each side,
left and right
• Select the stimulator
– Fill the edge information based
– Fill the anode and cathode
information
– Polarity
• Stimulators can have different
setting
• Can program multiple of these
stimulators at the same time

```

## Slide 24

### PowerPoint text

```text
24
Stimulation Mode - How
There are 64 stimulator in each side,left and right
Select the stimulator
Fill the edge information based
Fill the anode and cathode information
Polarity
Stimulators can have different setting
Can program multiple of these stimulators at the same time
Last we select the number of pulses we want to send (1-254) and click RUN

```

### PDF text

```text
RISE
24
Stimulation Mode - How
• There are 64 stimulator in each side,
left and right
• Select the stimulator
– Fill the edge information based
– Fill the anode and cathode
information
– Polarity
• Stimulators can have different
setting
• Can program multiple of these
stimulators at the same time
• Last we select the number of pulses
we want to send (1-254) and click
RUN

```

## Slide 25

### PowerPoint text

```text
25
What happens in the background
Firstly, an SPI excel file is loaded to the FPGA which then sends the data to the ASIC
The SPI has 4 data pins <CLK, L, R, LATCH>
L and R contains information for the stimulators programming and the gain of the amplifiers.

```

### PDF text

```text
RISE
25
What happens in the background
• Firstly, an SPI excel file is loaded to the FPGA
which then sends the data to the ASIC
– The SPI has 4 data pins <CLK, L, R, LATCH>
– L and R contains information for the stimulators
programming and the gain of the amplifiers.

```

## Slide 26

### PowerPoint text

```text
26
What happens in the background
Firstly, an SPI excel file is loaded to the FPGA which then sends the data to the ASIC
The SPI has 4 data pins <CLK, L, R, LATCH>
L and R contains information for the stimulators programming and the gain of the amplifiers.
Another patch reads the data in these two excel files and generates the right SPI stream file that downloads to the FPGA

SPI Stream
STIM Config
Gain Config
```

### PDF text

```text
RISE
26
What happens in the background
• Firstly, an SPI excel file is loaded to the FPGA
which then sends the data to the ASIC
– The SPI has 4 data pins <CLK, L, R, LATCH>
– L and R contains information for the
stimulators programming and the gain of the
amplifiers.
– Another patch reads the data in these two
excel files and generates the right SPI stream
file that downloads to the FPGA
SPI StreamSTIM ConfigGain Config
```

## Slide 27

### PowerPoint text

```text
27
What happens in the background
Firstly, an SPI excel file is loaded to the FPGA which then sends the data to the ASIC
The SPI has 4 data pins <CLK, L, R, LATCH>
L and R contains information for the stimulators programming and the gain of the amplifiers.
Another patch reads the data in these two excel files and generates the right SPI stream file that downloads to the FPGA
How does the stimulator start working?
Firstly, we enable the stims via STIM_EN
Then we send a short pulse to trigger the stims  STIM_START
After 64 STIM_CLK cycles, we enable STIM_CHB which does the charge balancing

```

### PDF text

```text
RISE
27
What happens in the background
• Firstly, an SPI excel file is loaded to the FPGA
which then sends the data to the ASIC
– The SPI has 4 data pins <CLK, L, R, LATCH>
– L and R contains information for the
stimulators programming and the gain of the
amplifiers.
– Another patch reads the data in these two
excel files and generates the right SPI stream
file that downloads to the FPGA
• How does the stimulator start working?
– Firstly, we enable the stims via STIM_EN
– Then we send a short pulse to trigger the
stims  STIM_START
– After 64 STIM_CLK cycles, we enable
STIM_CHB which does the charge balancing

```

## Slide 28

### PowerPoint text

```text
28
Different Stim patterns each cycle?
Firstly, an SPI excel file is loaded to the FPGA which then sends the data to the ASIC
The SPI has 4 data pins <CLK, L, R, LATCH>
L and R contains information for the stimulators programming and the gain of the amplifiers.
Another patch reads the data in these two excel files and generates the right SPI stream file that downloads to the FPGA
How does the stimulator start working?
Firstly, we enable the stims via STIM_EN
Then we send a short pulse to trigger the stims  STIM_START
After 64 STIM_CLK cycles, we enable STIM_CHB which does the charge balancing
Different stimulation sequence is possible as long as we can generate the timing diagram shown in the right

```

### PDF text

```text
RISE
28
Different Stim patterns each cycle?
• Firstly, an SPI excel file is loaded to the FPGA
which then sends the data to the ASIC
– The SPI has 4 data pins <CLK, L, R, LATCH>
– L and R contains information for the
stimulators programming and the gain of the
amplifiers.
– Another patch reads the data in these two
excel files and generates the right SPI stream
file that downloads to the FPGA
• How does the stimulator start working?
– Firstly, we enable the stims via STIM_EN
– Then we send a short pulse to trigger the
stims  STIM_START
– After 64 STIM_CLK cycles, we enable
STIM_CHB which does the charge balancing
• Different stimulation sequence is possible as
long as we can generate the timing diagram
shown in the right

```

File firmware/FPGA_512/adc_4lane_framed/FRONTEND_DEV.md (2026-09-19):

# ADC 512-Channel Frontend Development Kit

This bundle lets you develop against the 512-channel ADC pipeline without
hardware. A 1-minute recording from the real chip is included; the daemon
replays it in a loop at real-time pace, serving the same Unix socket API
that live hardware uses.

## Quick Start

```bash
# 1. Install the FTDI D3XX library (needed to link the daemon)
#    macOS: copy libftd3xx.dylib to /usr/local/lib and ftd3xx.h to /usr/local/include
#    Linux: see https://ftdichip.com/drivers/d3xx-drivers/

# 2. Build
cd adc_4lane_framed
make adc_daemon adc_ctl

# 3. Run the daemon in replay mode (loops the recording forever)
./adc_daemon --file /tmp/adc_1min.bin

# 4. In another terminal, verify it's working
./adc_ctl stats

# 5. Launch the live Python UI (optional, requires matplotlib + numpy)
python3 adc_live.py
```

The daemon listens on `/tmp/adc_daemon.sock`. Your frontend connects there.

---

## System Overview

```
512 channels = 8 data lines (D1-D8) x 64 amplifiers
Sample rate  = 15,625 Hz per channel
Resolution   = 12-bit ADC, stored as 16-bit signed PCM
Total data   = 16.5 MB/s raw USB, ~16 MB/s decoded
```

The FPGA deserializes 8 ADC serial streams into 4 framed lanes (2 channels
per lane), interleaves them into a single USB stream, and the daemon decodes
it into 512-channel "slices" at 15,625 Hz.

---

## Daemon Socket API

Connect to Unix socket `/tmp/adc_daemon.sock` (stream). The protocol is
line-based text. Send a command terminated by `\n`, read lines until you
see `ok` or `err`.

### Commands

| Command | Syntax | Response |
|---|---|---|
| Board control | `cmd <name>` | `ok` |
| Start recording | `record start <path> <chans>` | `ok recording N channels -> <path>` |
| Stop recording | `record stop` | `ok recorded N slices (Xs, M ch) -> <path> (errors=E drops=D)` |
| Statistics | `stats` | Multi-line report, ends with `ok` |
| Plot stream | `plot <chans> <decim> [minmax]` | `ok plot N channels decim D [minmax]` then binary |
| Shutdown | `quit` | `ok shutting down` |

Unknown commands return: `err unknown verb (cmd/record/stats/plot/quit)`

### Board Commands (`cmd <name>`)

| Name | Opcode | Effect |
|---|---|---|
| `chip-reset` | 0x11 | Pulse ADC chip reset |
| `fe-pulse` | 0x21 | Pulse front-end reset |
| `fe-on` | 0x22 | FE reset high (test mode, outputs midscale ~2048) |
| `fe-off` | 0x23 | FE reset low (normal operation) |
| `pattern-on` | 0x31 | Inject +1 ramp pattern (replaces real ADC data) |
| `pattern-off` | 0x32 | Back to real ADC data |
| `spi` | 0x41 | Run SPI init sequence |

In replay mode, board commands are acknowledged but have no effect (no hardware).

### Channel Selection Syntax

Used by `record start` and `plot`:

- `all` -- all 512 channels (0-511)
- `0-63` -- range (inclusive)
- `0-63,320,384-447` -- comma-separated ranges and singles

### Stats Response Format

```
up 62.9 s  in 990.0 MB (15.7 MB/s)  slices 981875 (62.8 s)  ring 5%  overruns 0  hunt 0
lane 0: frames=245468 crc=0 seq=0 lane_id=0 drops=60
lane 1: frames=245468 crc=0 seq=0 lane_id=0 drops=60
lane 2: frames=245468 crc=0 seq=0 lane_id=0 drops=81
lane 3: frames=245468 crc=0 seq=0 lane_id=0 drops=75
read gaps >1.5/3/6/12ms: 0/0/0/0  max 0.00 ms  out-max 0.00 ms
partial 0  filler 0
ok
```

### Async Events

While in text mode (before switching to `plot`), the daemon pushes async
events to all connected clients. These are lines starting with `!`:

```
!drops lane=2 n=5 total=37       FPGA-side sample drops (FIFO overflow)
!crc lane=0 total=3              CRC-12 mismatch (corrupted frame)
!seq lane=1 total=2              Sequence gap (missing frame)
!lane_id lane=3 total=1          Bad LANE_ID field
!usb read error status=-3        USB pipe error
```

---

## Binary Plot Stream Protocol

After sending `plot <chans> <decim> [minmax]` and receiving the `ok` line,
the connection switches to binary. The daemon pushes packets continuously.

### Packet Format

All fields are **little-endian**.

```
Offset  Size   Field      Description
0       u32    magic      0x41444350 ("ADCP")
4       u32    seq        Monotonic packet sequence number
8       u16    n_ch       Number of int16 values per time bin
10      u16    n_slices   Number of time bins in this packet
12      ...    data       int16[n_slices][n_ch]
```

**Total packet size** = 12 + n_slices * n_ch * 2 bytes.
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

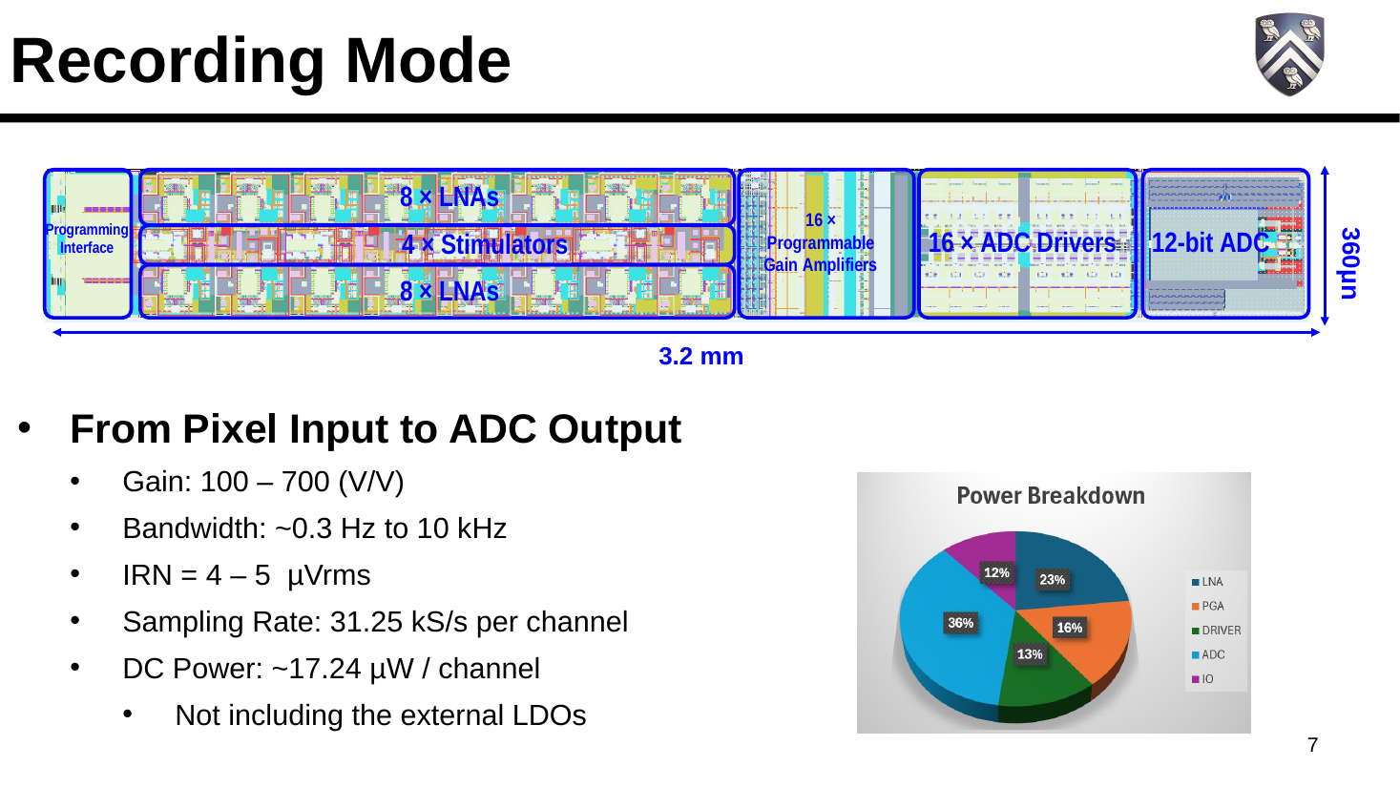
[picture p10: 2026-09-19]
sources/slides/previews/slide-07.png

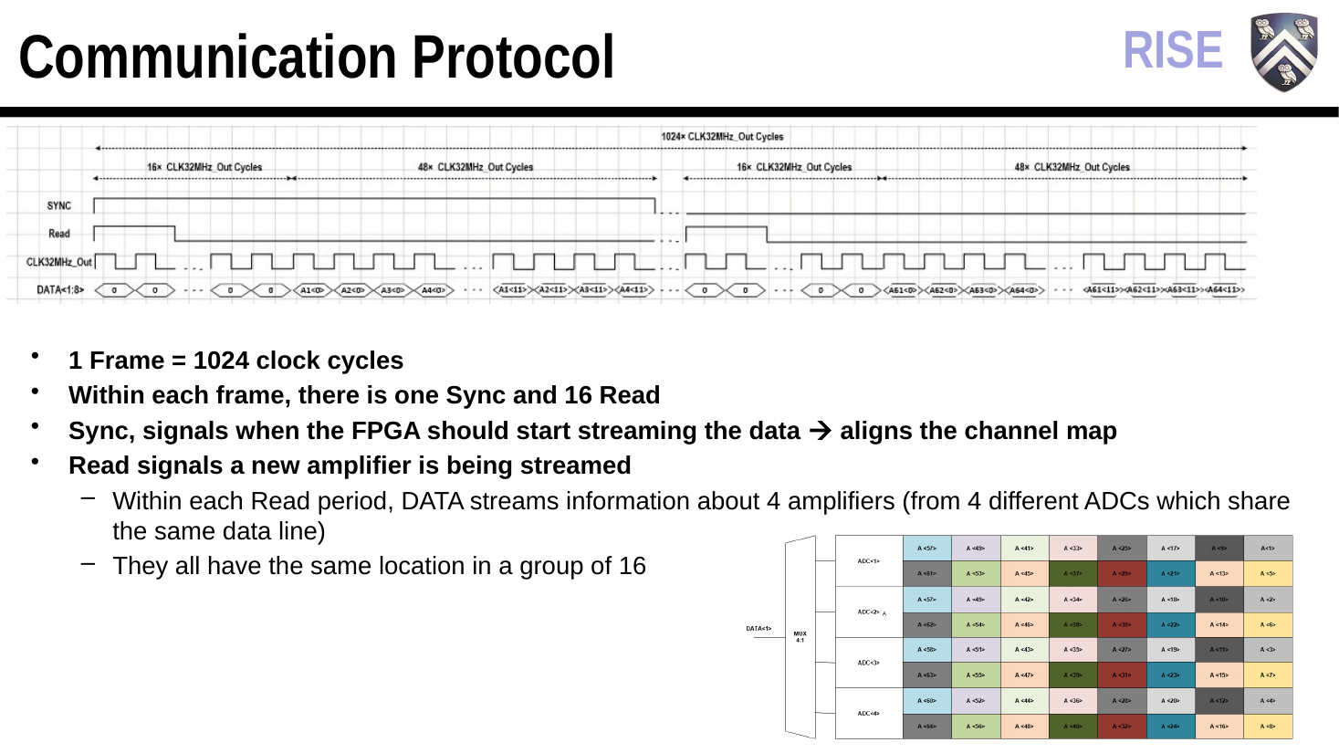
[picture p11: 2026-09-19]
sources/slides/previews/slide-17.png

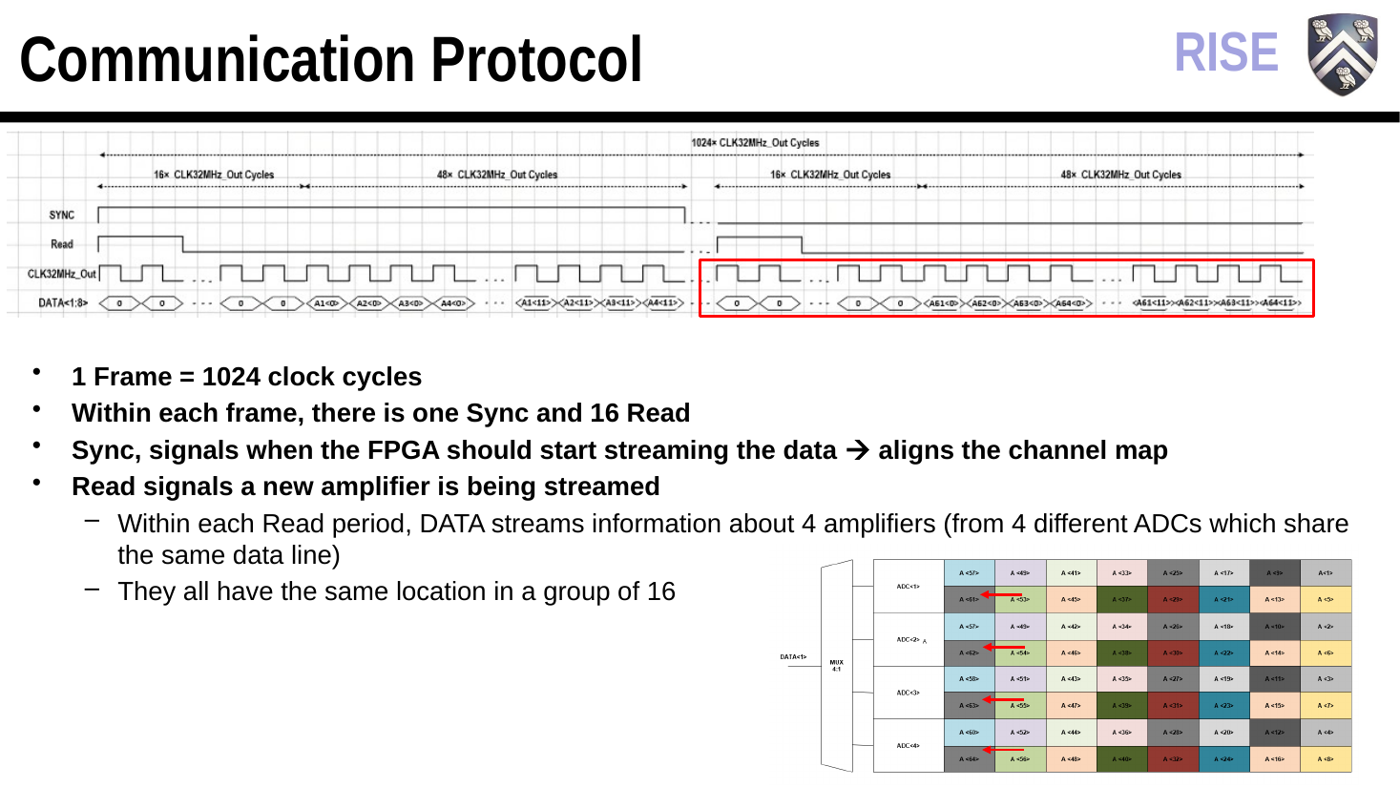
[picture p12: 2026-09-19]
sources/slides/previews/slide-16.png

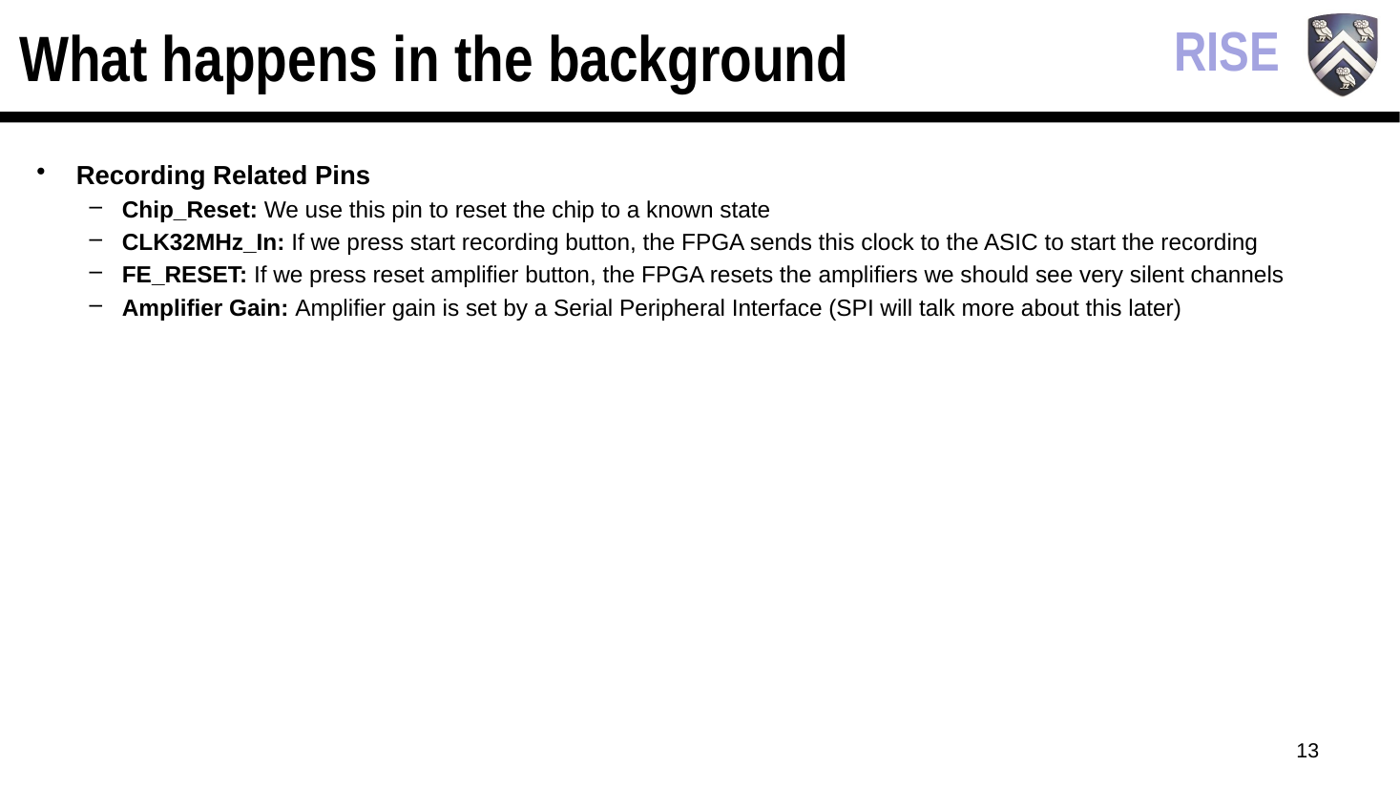
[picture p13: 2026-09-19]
sources/slides/previews/slide-13.png

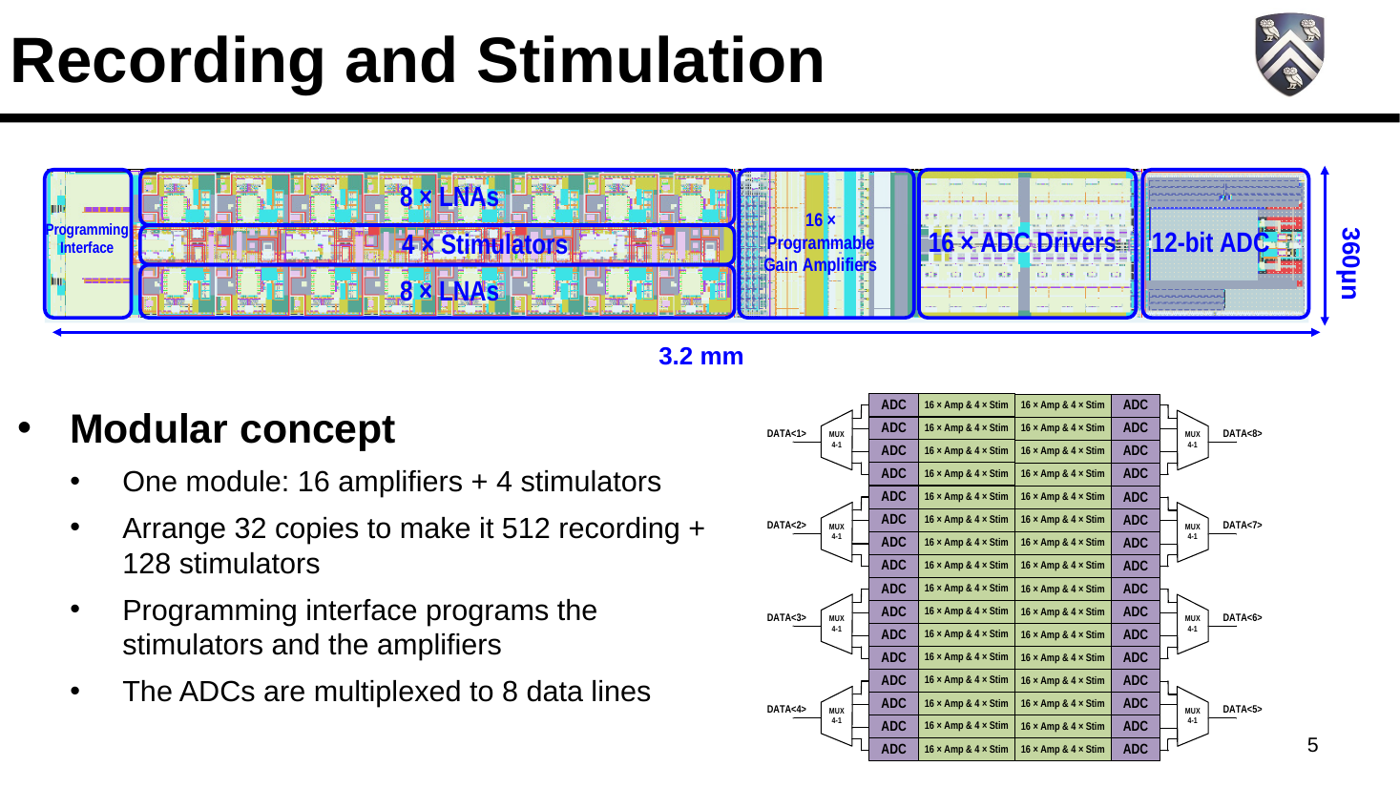
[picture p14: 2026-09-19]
sources/slides/previews/slide-05.png

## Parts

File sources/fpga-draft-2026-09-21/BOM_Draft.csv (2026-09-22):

Reference | Value | MPN | Manufacturer | Footprint | Group | Tolerance | Voltage rating | Power rating | Temperature | Status | Qualification | Datasheet | DNP | Purchasable design item | X mm | Y mm | Side
U1 | XC7A200T-1SBG484C | XC7A200T-1SBG484C | TBD | Howard:Xilinx_SBG484__U1 | FPGA physical pins | TBD | TBD | TBD | TBD | XC7A200T device selection confirmed by user on 2026-09-21; 484 physical pins verified; bank/application plan incomplete | Review component ratings, pin map and circuit function before release. | https://docs.amd.com/v/u/en-US/ug475_7Series_Pkg_Pinout | False | True | 16.4 | 14.6 | Top
U2 | S25FL256SAGMFI000 | S25FL256SAGMFI000 | TBD | Howard:SOIC-16W_7.5x10.3mm_P1.27mm__U2 | Boot flash and JTAG | TBD | TBD | TBD | TBD | PROPOSED | Exact model 00: RESET and VIO are not brought out. RFU and DNU left unconnected by design. Do not substitute a G/R model without review. | https://www.infineon.com/assets/row/public/documents/10/49/infineon-s25fl128s-s25fl256s-128-mb-16-mb-256-mb-32-mb-fl-s-flash-spi-multi-io-3-v-datasheet-en.pdf | False | True | 6.5 | 18.100001 | Bottom
J4 | JTAG_CUSTOM_2x3_1.27mm | TBD | TBD | Howard:PinHeader_2x03_P1.27mm_Vertical__J4 | Boot flash and JTAG | TBD | TBD | TBD | TBD | PROPOSED | Custom pin map: requires documented adapter to external programmer. VTREF senses target 3.3 V; not a power input. No direct Digilent/ARM pinout compatibility claimed. |  | False | True | 2.664999 | 28.63 | Top
SW1 | PROGRAM_B_RESET | TBD | TBD | Howard:SW_SPST_TL3305A__SW1 | Boot flash and JTAG | TBD | TBD | TBD | TBD | PROPOSED | Candidate footprint; exact switch order code must be checked against mechanical drawing. |  | False | True | 7.825001 | 28.796001 | Bottom
R101 | 4.7kOhm | CRCW02014K70FKED | Vishay | Howard:R_0201_0603Metric__R101 | Boot flash and JTAG | 1% | 30 V limiting voltage | 0.05 W at 70 C; derate above | -55 to +155 C | PROPOSED_POPULATE | 0201 assembly process and solder inspection required; series resistor tuning after SI review. | https://www.vishay.com/doc/?20052= | False | True | 12.475 | 19.625 | Bottom
R102 | 4.7kOhm | CRCW02014K70FKED | Vishay | Howard:R_0201_0603Metric__R102 | Boot flash and JTAG | 1% | 30 V limiting voltage | 0.05 W at 70 C; derate above | -55 to +155 C | PROPOSED_POPULATE | 0201 assembly process and solder inspection required; series resistor tuning after SI review. | https://www.vishay.com/doc/?20052= | False | True | 8.325 | 11.575 | Bottom
R103 | 10kOhm | CRCW020110K0FKED | Vishay | Howard:R_0201_0603Metric__R103 | Boot flash and JTAG | 1% | 30 V limiting voltage | 0.05 W at 70 C; derate above | -55 to +155 C | PROPOSED_POPULATE | 0201 assembly process and solder inspection required; series resistor tuning after SI review. | https://www.vishay.com/doc/?20052= | False | True | 1.875 | 18.425 | Top
R104 | 4.7kOhm | CRCW02014K70FKED | Vishay | Howard:R_0201_0603Metric__R104 | Boot flash and JTAG | 1% | 30 V limiting voltage | 0.05 W at 70 C; derate above | -55 to +155 C | PROPOSED_POPULATE | 0201 assembly process and solder inspection required; series resistor tuning after SI review. | https://www.vishay.com/doc/?20052= | False | True | 3.325 | 24.575 | Bottom
R105 | 4.7kOhm | CRCW02014K70FKED | Vishay | Howard:R_0201_0603Metric__R105 | Boot flash and JTAG | 1% | 30 V limiting voltage | 0.05 W at 70 C; derate above | -55 to +155 C | PROPOSED_POPULATE | 0201 assembly process and solder inspection required; series resistor tuning after SI review. | https://www.vishay.com/doc/?20052= | False | True | 1.875 | 20.025 | Top
R106 | 4.7kOhm | CRCW02014K70FKED | Vishay | Howard:R_0201_0603Metric__R106 | Boot flash and JTAG | 1% | 30 V limiting voltage | 0.05 W at 70 C; derate above | -55 to +155 C | PROPOSED_POPULATE | 0201 assembly process and solder inspection required; series resistor tuning after SI review. | https://www.vishay.com/doc/?20052= | False | True | 2.725 | 22.275 | Top
R107 | 1kOhm | CRCW02011K00FKED | Vishay | Howard:R_0201_0603Metric__R107 | Boot flash and JTAG | 1% | 30 V limiting voltage | 0.05 W at 70 C; derate above | -55 to +155 C | PROPOSED_POPULATE | 0201 assembly process and solder inspection required; series resistor tuning after SI review. | https://www.vishay.com/doc/?20052= | False | True | 0.875 | 18.425 | Top
R108 | 1kOhm | CRCW02011K00FKED | Vishay | Howard:R_0201_0603Metric__R108 | Boot flash and JTAG | 1% | 30 V limiting voltage | 0.05 W at 70 C; derate above | -55 to +155 C | PROPOSED_POPULATE | 0201 assembly process and solder inspection required; series resistor tuning after SI review. | https://www.vishay.com/doc/?20052= | False | True | 3.325 | 25.475 | Bottom
R109 | 1kOhm | CRCW02011K00FKED | Vishay | Howard:R_0201_0603Metric__R109 | Boot flash and JTAG | 1% | 30 V limiting voltage | 0.05 W at 70 C; derate above | -55 to +155 C | PROPOSED_POPULATE | 0201 assembly process and solder inspection required; series resistor tuning after SI review. | https://www.vishay.com/doc/?20052= | False | True | 0.775 | 16.725 | Top
R110 | 1kOhm | CRCW02011K00FKED | Vishay | Howard:R_0201_0603Metric__R110 | Boot flash and JTAG | 1% | 30 V limiting voltage | 0.05 W at 70 C; derate above | -55 to +155 C | PROPOSED_POPULATE | 0201 assembly process and solder inspection required; series resistor tuning after SI review. | https://www.vishay.com/doc/?20052= | False | True | 1.725 | 24.575 | Bottom
R111 | 22Ohm | CRCW020122R0FNED | Vishay | Howard:R_0201_0603Metric__R111 | Boot flash and JTAG | 1% | 30 V limiting voltage | 0.05 W at 70 C; derate above | -55 to +155 C | PROPOSED_POPULATE | 0201 assembly process and solder inspection required; series resistor tuning after SI review. | https://www.vishay.com/doc/?20052= | False | True | 1.525 | 21.275 | Top
R112 | 0Ohm | CRCW02010000Z0ED | Vishay | Howard:R_0201_0603Metric__R112 | Boot flash and JTAG | jumper <=50mOhm | 30 V limiting voltage | 0.05 W at 70 C; derate above | -55 to +155 C | PROPOSED_POPULATE | 0201 assembly process and solder inspection required; series resistor tuning after SI review. | https://www.vishay.com/doc/?20052= | False | True | 0.875 | 20.025 | Top
R113 | 0Ohm | CRCW02010000Z0ED | Vishay | Howard:R_0201_0603Metric__R113 | Boot flash and JTAG | jumper <=50mOhm | 30 V limiting voltage | 0.05 W at 70 C; derate above | -55 to +155 C | PROPOSED_POPULATE | 0201 assembly process and solder inspection required; series resistor tuning after SI review. | https://www.vishay.com/doc/?20052= | False | True | 2.725 | 23.175 | Top
R114 | 0Ohm | CRCW02010000Z0ED | Vishay | Howard:R_0201_0603Metric__R114 | Boot flash and JTAG | jumper <=50mOhm | 30 V limiting voltage | 0.05 W at 70 C; derate above | -55 to +155 C | PROPOSED_POPULATE | 0201 assembly process and solder inspection required; series resistor tuning after SI review. | https://www.vishay.com/doc/?20052= | False | True | 4.925 | 24.275 | Top
R115 | 0Ohm | CRCW02010000Z0ED | Vishay | Howard:R_0201_0603Metric__R115 | Boot flash and JTAG | jumper <=50mOhm | 30 V limiting voltage | 0.05 W at 70 C; derate above | -55 to +155 C | PROPOSED_POPULATE | 0201 assembly process and solder inspection required; series resistor tuning after SI review. | https://www.vishay.com/doc/?20052= | False | True | 0.775 | 15.125 | Top
C101 | 100nF | C1005X7R1C104K050BC | TDK | Howard:C_0402_1005Metric__C101 | Boot flash and JTAG | 10% | 16 V | TBD | -55 to +125 C; X7R | PROPOSED | Local flash bypass candidate; verify DC bias. | https://product.tdk.com/en/search/capacitor/ceramic/mlcc/info?part_no=C1005X7R1C104K050BC | False | True | 12.585 | 15.635 | Bottom
C102 | 1uF | C1005X5R1V105K050BC | TDK | Howard:C_0402_1005Metric__C102 | Boot flash and JTAG | 10% | 35 V | TBD | -55 to +85 C; X5R | PROPOSED | Local flash bulk candidate; verify DC bias and temperature. | https://product.tdk.com/en/search/capacitor/ceramic/mlcc/info?part_no=C1005X5R1V105K050BC | False | True | 6.535 | 11.485 | Bottom
Y1 | Oscillator frequency / MPN TBD | TBD | TBD | Howard:Oscillator_SMD_Abracon_ASE-4Pin_3.2x2.5mm__Y1 | Clock and startup | TBD | TBD | TBD | TBD | RESERVATION_ONLY / ELECTRICAL REQUIREMENTS TBD | Review component ratings, pin map and circuit function before release. |  | False | True | 30.0 | 2.8 | Top
R120 | TBD clock series resistor | TBD | TBD | Howard:R_0402_1005Metric__R120 | Clock and startup | TBD | TBD | TBD | TBD | RESERVATION_ONLY / ELECTRICAL REQUIREMENTS TBD | Review component ratings, pin map and circuit function before release. |  | False | True | 27.795 | 5.655 | Top
R121 | TBD oscillator control resistor | TBD | TBD | Howard:R_0402_1005Metric__R121 | Clock and startup | TBD | TBD | TBD | TBD | RESERVATION_ONLY / ELECTRICAL REQUIREMENTS TBD | Review component ratings, pin map and circuit function before release. |  | False | True | 34.955 | 1.295 | Top
C120 | TBD oscillator bypass | TBD | TBD | Howard:C_0603_1608Metric__C120 | Clock and startup | TBD | TBD | TBD | TBD | RESERVATION_ONLY / ELECTRICAL REQUIREMENTS TBD | Review component ratings, pin map and circuit function before release. |  | False | True | 30.005 | 5.455 | Top
R130 | 0R / DNP | TBD | TBD | Howard:R_0402_1005Metric__R130 | Bank voltage options | TBD | TBD | TBD | TBD | DNP voltage-option proposal; do not populate before bank/interface review | Review component ratings, pin map and circuit function before release. |  | True | True | 29.955 | 4.695 | Bottom
R131 | 0R / DNP | TBD | TBD | Howard:R_0402_1005Metric__R131 | Bank voltage options | TBD | TBD | TBD | TBD | DNP voltage-option proposal; do not populate before bank/interface review | Review component ratings, pin map and circuit function before release. |  | True | True | 29.955 | 1.295 | Bottom
R132 | 0R / DNP | TBD | TBD | Howard:R_0402_1005Metric__R132 | Bank voltage options | TBD | TBD | TBD | TBD | DNP voltage-option proposal; do not populate before bank/interface review | Review component ratings, pin map and circuit function before release. |  | True | True | 27.755 | 1.795 | Bottom
R133 | 0R / DNP | TBD | TBD | Howard:R_0402_1005Metric__R133 | Bank voltage options | TBD | TBD | TBD | TBD | DNP voltage-option proposal; do not populate before bank/interface review | Review component ratings, pin map and circuit function before release. |  | True | True | 32.055 | 4.695 | Bottom
R134 | 0R / DNP | TBD | TBD | Howard:R_0402_1005Metric__R134 | Bank voltage options | TBD | TBD | TBD | TBD | DNP voltage-option proposal; do not populate before bank/interface review | Review component ratings, pin map and circuit function before release. |  | True | True | 32.055 | 1.295 | Bottom
U4 | ADP5052ACPZ-R7 | ADP5052ACPZ-R7 | TBD | Howard:ADP5052_CP48_13_DRAFT__U4 | Power conversion | TBD | TBD | TBD | TBD | pin_map_verified_design_proposed; land pattern/paste/thermal-via geometry not released | Review component ratings, pin map and circuit function before release. | https://www.analog.com/media/en/technical-documentation/data-sheets/ADP5052.PDF | False | True | 22.0 | 23.4 | Bottom
Q1 | Si7232DN-T1-GE3 - ONE dual NFET package | Si7232DN-T1-GE3 | TBD | Howard:Vishay_PowerPAK_1212-8_Dual__Q1 | Power conversion | TBD | TBD | TBD | TBD | pin_map_verified_candidate | Review component ratings, pin map and circuit function before release. | https://www.vishay.com/docs/68986/si7232dn.pdf | False | True | 14.8 | 23.4 | Bottom
L1 | 3.3 uH proposed | XAL6030-332MEC | TBD | Howard:L_Coilcraft_XAL6030-XXX__L1 | Power conversion | TBD | TBD | TBD | TBD | calculated_inductance_candidate_mpn | Review component ratings, pin map and circuit function before release. | https://www.coilcraft.com/en-us/products/power/shielded-inductors/molded-inductor/xal/ | False | True | 27.75 | 30.37 | Top
R301 | 2.49k 0.1% | TBD | TBD | Howard:R_0402_1005Metric__R301 | Power conversion | TBD | TBD | TBD | TBD | proposed | Review component ratings, pin map and circuit function before release. |  | False | True | 21.955 | 18.695 | Bottom
R302 | 10k 0.1% | TBD | TBD | Howard:R_0402_1005Metric__R302 | Power conversion | TBD | TBD | TBD | TBD | proposed | Review component ratings, pin map and circuit function before release. |  | False | True | 26.695 | 26.855 | Bottom
C301 | 100nF 16V X7R | TBD | TBD | Howard:C_0402_1005Metric__C301 | Power conversion | TBD | TBD | TBD | TBD | proposed | Review component ratings, pin map and circuit function before release. |  | False | True | 11.435 | 24.685 | Bottom
C305 | 10uF 25V X5R/X7R | TBD | TBD | Howard:C_1206_3216Metric__C305 | Power conversion | TBD | TBD | TBD | TBD | proposed | Review component ratings, pin map and circuit function before release. |  | False | True | 21.425 | 26.475 | Top
R309 | TBD compensation R | TBD | TBD | Howard:R_0402_1005Metric__R309 | Power conversion | TBD | TBD | TBD | TBD | TBD_NOT_RELEASED | Review component ratings, pin map and circuit function before release. |  | False | True | 21.955 | 17.495 | Bottom
C311 | TBD compensation C | TBD | TBD | Howard:C_0402_1005Metric__C311 | Power conversion | TBD | TBD | TBD | TBD | TBD_NOT_RELEASED | Review component ratings, pin map and circuit function before release. |  | False | True | 30.885 | 31.635 | Bottom
C315 | DNP optional compensation pole C | TBD | TBD | Howard:C_0402_1005Metric__C315 | Power conversion | TBD | TBD | TBD | TBD | OPTIONAL_TBD | Review component ratings, pin map and circuit function before release. |  | True | True | 12.885 | 29.635 | Top
L2 | 4.7 uH proposed | XAL6060-472MEC | TBD | Howard:L_Coilcraft_XAL6060-XXX__L2 | Power conversion | TBD | TBD | TBD | TBD | calculated_inductance_candidate_mpn | Review component ratings, pin map and circuit function before release. | https://www.coilcraft.com/en-us/products/power/shielded-inductors/molded-inductor/xal/ | False | True | 26.7 | 15.0 | Bottom
R303 | 12.7k 0.1% | TBD | TBD | Howard:R_0402_1005Metric__R303 | Power conversion | TBD | TBD | TBD | TBD | proposed | Review component ratings, pin map and circuit function before release. |  | False | True | 24.855 | 25.795 | Top
R304 | 10.2k 0.1% | TBD | TBD | Howard:R_0402_1005Metric__R304 | Power conversion | TBD | TBD | TBD | TBD | proposed | Review component ratings, pin map and circuit function before release. |  | False | True | 27.795 | 26.855 | Bottom
C302 | 100nF 16V X7R | TBD | TBD | Howard:C_0402_1005Metric__C302 | Power conversion | TBD | TBD | TBD | TBD | proposed | Review component ratings, pin map and circuit function before release. |  | False | True | 34.585 | 23.435 | Bottom
C306 | 10uF 25V X5R/X7R | TBD | TBD | Howard:C_1206_3216Metric__C306 | Power conversion | TBD | TBD | TBD | TBD | proposed | Review component ratings, pin map and circuit function before release. |  | False | True | 15.425 | 20.175 | Bottom
R310 | TBD compensation R | TBD | TBD | Howard:R_0402_1005Metric__R310 | Power conversion | TBD | TBD | TBD | TBD | TBD_NOT_RELEASED | Review component ratings, pin map and circuit function before release. |  | False | True | 18.495 | 26.255 | Top
C312 | TBD compensation C | TBD | TBD | Howard:C_0402_1005Metric__C312 | Power conversion | TBD | TBD | TBD | TBD | TBD_NOT_RELEASED | Review component ratings, pin map and circuit function before release. |  | False | True | 16.535 | 34.785 | Bottom
C316 | DNP optional compensation pole C | TBD | TBD | Howard:C_0402_1005Metric__C316 | Power conversion | TBD | TBD | TBD | TBD | OPTIONAL_TBD | Review component ratings, pin map and circuit function before release. |  | True | True | 13.735 | 31.285 | Top
L3 | 10 uH proposed | XAL4040-103MEC | TBD | Howard:L_Coilcraft_XAL4040-XXX__L3 | Power conversion | TBD | TBD | TBD | TBD | calculated_inductance_candidate_mpn | Review component ratings, pin map and circuit function before release. | https://www.coilcraft.com/en-us/products/power/shielded-inductors/molded-inductor/xal/ | False | True | 17.0 | 31.7 | Bottom
R305 | 8.87k 0.1% | TBD | TBD | Howard:R_0402_1005Metric__R305 | Power conversion | TBD | TBD | TBD | TBD | proposed | Review component ratings, pin map and circuit function before release. |  | False | True | 21.955 | 16.295 | Bottom
R306 | 10.2k 0.1% | TBD | TBD | Howard:R_0402_1005Metric__R306 | Power conversion | TBD | TBD | TBD | TBD | proposed | Review component ratings, pin map and circuit function before release. |  | False | True | 28.895 | 26.855 | Bottom
C303 | 100nF 16V X7R | TBD | TBD | Howard:C_0402_1005Metric__C303 | Power conversion | TBD | TBD | TBD | TBD | proposed | Review component ratings, pin map and circuit function before release. |  | False | True | 24.035 | 35.985 | Bottom
C307 | 10uF 25V X5R/X7R | TBD | TBD | Howard:C_1206_3216Metric__C307 | Power conversion | TBD | TBD | TBD | TBD | proposed | Review component ratings, pin map and circuit function before release. |  | False | True | 29.425 | 25.575 | Top
R311 | TBD compensation R | TBD | TBD | Howard:R_0402_1005Metric__R311 | Power conversion | TBD | TBD | TBD | TBD | TBD_NOT_RELEASED | Review component ratings, pin map and circuit function before release. |  | False | True | 21.955 | 15.195 | Bottom
C313 | TBD compensation C | TBD | TBD | Howard:C_0402_1005Metric__C313 | Power conversion | TBD | TBD | TBD | TBD | TBD_NOT_RELEASED | Review component ratings, pin map and circuit function before release. |  | False | True | 16.935 | 33.885 | Top
C317 | DNP optional compensation pole C | TBD | TBD | Howard:C_0402_1005Metric__C317 | Power conversion | TBD | TBD | TBD | TBD | OPTIONAL_TBD | Review component ratings, pin map and circuit function before release. |  | True | True | 11.685 | 31.135 | Bottom
L4 | 22 uH proposed | XAL6060-223MEC | TBD | Howard:L_Coilcraft_XAL6060-XXX__L4 | Power conversion | TBD | TBD | TBD | TBD | calculated_inductance_candidate_mpn | Review component ratings, pin map and circuit function before release. | https://www.coilcraft.com/en-us/products/power/shielded-inductors/molded-inductor/xal/ | False | True | 26.7 | 31.7 | Bottom
R307 | 31.6k 0.1% | TBD | TBD | Howard:R_0402_1005Metric__R307 | Power conversion | TBD | TBD | TBD | TBD | proposed | Review component ratings, pin map and circuit function before release. |  | False | True | 21.955 | 14.095 | Bottom
R308 | 10.2k 0.1% | TBD | TBD | Howard:R_0402_1005Metric__R308 | Power conversion | TBD | TBD | TBD | TBD | proposed | Review component ratings, pin map and circuit function before release. |  | False | True | 13.895 | 29.755 | Bottom
C304 | 100nF 16V X7R | TBD | TBD | Howard:C_0402_1005Metric__C304 | Power conversion | TBD | TBD | TBD | TBD | proposed | Review component ratings, pin map and circuit function before release. |  | False | True | 18.635 | 35.885 | Bottom
C308 | 10uF 25V X5R/X7R | TBD | TBD | Howard:C_1206_3216Metric__C308 | Power conversion | TBD | TBD | TBD | TBD | proposed | Review component ratings, pin map and circuit function before release. |  | False | True | 11.775 | 27.725 | Bottom
R312 | TBD compensation R | TBD | TBD | Howard:R_0402_1005Metric__R312 | Power conversion | TBD | TBD | TBD | TBD | TBD_NOT_RELEASED | Review component ratings, pin map and circuit function before release. |  | False | True | 16.855 | 30.595 | Top
C314 | TBD compensation C | TBD | TBD | Howard:C_0402_1005Metric__C314 | Power conversion | TBD | TBD | TBD | TBD | TBD_NOT_RELEASED | Review component ratings, pin map and circuit function before release. |  | False | True | 31.985 | 31.635 | Bottom
C318 | DNP optional compensation pole C | TBD | TBD | Howard:C_0402_1005Metric__C318 | Power conversion | TBD | TBD | TBD | TBD | OPTIONAL_TBD | Review component ratings, pin map and circuit function before release. |  | True | True | 14.835 | 32.685 | Top
C309 | 1uF 10V X5R/X7R | TBD | TBD | Howard:C_0402_1005Metric__C309 | Power conversion | TBD | TBD | TBD | TBD | proposed | Review component ratings, pin map and circuit function before release. |  | False | True | 26.035 | 35.985 | Bottom
C310 | 1uF 10V X5R/X7R | TBD | TBD | Howard:C_0402_1005Metric__C310 | Power conversion | TBD | TBD | TBD | TBD | proposed | Review component ratings, pin map and circuit function before release. |  | False | True | 13.435 | 33.485 | Bottom
R313 | 68.1k 0.1% | TBD | TBD | Howard:R_0402_1005Metric__R313 | Power conversion | TBD | TBD | TBD | TBD | proposed | Review component ratings, pin map and circuit function before release. |  | False | True | 21.955 | 12.995 | Bottom
R314 | 22k 1% | TBD | TBD | Howard:R_0402_1005Metric__R314 | Power conversion | TBD | TBD | TBD | TBD | proposed | Review component ratings, pin map and circuit function before release. |  | False | True | 12.795 | 17.755 | Bottom
R315 | 22k 1% | TBD | TBD | Howard:R_0402_1005Metric__R315 | Power conversion | TBD | TBD | TBD | TBD | proposed | Review component ratings, pin map and circuit function before release. |  | False | True | 16.855 | 31.695 | Top
R316 | 10k 1% | TBD | TBD | Howard:R_0402_1005Metric__R316 | Power conversion | TBD | TBD | TBD | TBD | proposed | Review component ratings, pin map and circuit function before release. |  | False | True | 33.495 | 23.455 | Bottom
R317 | 100k 1% | TBD | TBD | Howard:R_0402_1005Metric__R317 | Power conversion | TBD | TBD | TBD | TBD | proposed | Review component ratings, pin map and circuit function before release. |  | False | True | 21.955 | 11.895 | Bottom
R318 | 115k 1% | TBD | TBD | Howard:R_0402_1005Metric__R318 | Power conversion | TBD | TBD | TBD | TBD | proposed | Review component ratings, pin map and circuit function before release. |  | False | True | 13.995 | 29.655 | Top
R319 | 10k 1% | TBD | TBD | Howard:R_0402_1005Metric__R319 | Power conversion | TBD | TBD | TBD | TBD | proposed | Review component ratings, pin map and circuit function before release. |  | False | True | 15.295 | 31.055 | Top
R320 | 10k 1% | TBD | TBD | Howard:R_0402_1005Metric__R320 | Power conversion | TBD | TBD | TBD | TBD | proposed | Review component ratings, pin map and circuit function before release. |  | False | True | 13.895 | 31.855 | Bottom
R321 | 10k 1% | TBD | TBD | Howard:R_0402_1005Metric__R321 | Power conversion | TBD | TBD | TBD | TBD | proposed | Review component ratings, pin map and circuit function before release. |  | False | True | 18.555 | 34.795 | Bottom
R322 | DNP soft-start top option | TBD | TBD | Howard:R_0402_1005Metric__R322 | Power conversion | TBD | TBD | TBD | TBD | OPTIONAL_TBD | Review component ratings, pin map and circuit function before release. |  | True | True | 32.395 | 25.355 | Top
R323 | 0R - 8ms soft start | TBD | TBD | Howard:R_0402_1005Metric__R323 | Power conversion | TBD | TBD | TBD | TBD | proposed | Review component ratings, pin map and circuit function before release. |  | False | True | 16.855 | 32.795 | Top
R324 | DNP soft-start top option | TBD | TBD | Howard:R_0402_1005Metric__R324 | Power conversion | TBD | TBD | TBD | TBD | OPTIONAL_TBD | Review component ratings, pin map and circuit function before release. |  | True | True | 12.795 | 31.155 | Bottom
R325 | 0R - 8ms soft start | TBD | TBD | Howard:R_0402_1005Metric__R325 | Power conversion | TBD | TBD | TBD | TBD | proposed | Review component ratings, pin map and circuit function before release. |  | False | True | 33.955 | 25.095 | Bottom
C319 | 100uF 6.3V local-output PROVISIONAL | TBD | TBD | Howard:C_1210_3225Metric__C319 | Power conversion | TBD | TBD | TBD | TBD | PROVISIONAL_CAPACITANCE_LEDGER_REVIEW | Review component ratings, pin map and circuit function before release. |  | False | True | 27.825 | 23.425 | Bottom
C320 | 100uF 6.3V local-output PROVISIONAL | TBD | TBD | Howard:C_1210_3225Metric__C320 | Power conversion | TBD | TBD | TBD | TBD | PROVISIONAL_CAPACITANCE_LEDGER_REVIEW | Review component ratings, pin map and circuit function before release. |  | False | True | 21.325 | 29.925 | Bottom
C321 | 47uF 6.3V local-output PROVISIONAL | TBD | TBD | Howard:C_1210_3225Metric__C321 | Power conversion | TBD | TBD | TBD | TBD | PROVISIONAL_CAPACITANCE_LEDGER_REVIEW | Review component ratings, pin map and circuit function before release. |  | False | True | 15.425 | 27.025 | Bottom
C322 | 47uF 6.3V local-output PROVISIONAL | TBD | TBD | Howard:C_1210_3225Metric__C322 | Power conversion | TBD | TBD | TBD | TBD | PROVISIONAL_CAPACITANCE_LEDGER_REVIEW | Review component ratings, pin map and circuit function before release. |  | False | True | 16.225 | 27.625 | Top
C323 | 47uF 6.3V local-output PROVISIONAL | TBD | TBD | Howard:C_1210_3225Metric__C323 | Power conversion | TBD | TBD | TBD | TBD | PROVISIONAL_CAPACITANCE_LEDGER_REVIEW | Review component ratings, pin map and circuit function before release. |  | False | True | 31.225 | 23.425 | Bottom
C324 | 22uF 6.3V local-output PROVISIONAL | TBD | TBD | Howard:C_1210_3225Metric__C324 | Power conversion | TBD | TBD | TBD | TBD | PROVISIONAL_CAPACITANCE_LEDGER_REVIEW | Review component ratings, pin map and circuit function before release. |  | False | True | 32.025 | 18.625 | Bottom
C325 | 22uF 6.3V local-output PROVISIONAL | TBD | TBD | Howard:C_1210_3225Metric__C325 | Power conversion | TBD | TBD | TBD | TBD | PROVISIONAL_CAPACITANCE_LEDGER_REVIEW | Review component ratings, pin map and circuit function before release. |  | False | True | 32.025 | 28.225 | Bottom
C326 | 22uF 6.3V local-output PROVISIONAL | TBD | TBD | Howard:C_1210_3225Metric__C326 | Power conversion | TBD | TBD | TBD | TBD | PROVISIONAL_CAPACITANCE_LEDGER_REVIEW | Review component ratings, pin map and circuit function before release. |  | False | True | 21.325 | 34.725 | Bottom
C327 | 22uF 6.3V local-output PROVISIONAL | TBD | TBD | Howard:C_1210_3225Metric__C327 | Power conversion | TBD | TBD | TBD | TBD | PROVISIONAL_CAPACITANCE_LEDGER_REVIEW | Review component ratings, pin map and circuit function before release. |  | False | True | 12.125 | 26.925 | Top
U3 | Recording RAM / exact part TBD | TBD | TBD | Howard:Micron_FBGA-96_8x14mm_Layout9x16_P0.8mm__U3 | Recording memory reservation | TBD | TBD | TBD | TBD | RESERVATION_ONLY / ELECTRICAL REQUIREMENTS TBD | Review component ratings, pin map and circuit function before release. |  | False | True | 33.0 | 16.2 | Top
J1 | Routing 80-contact / proxy | TBD | TBD | Howard:Hirose_DF40C-80DS-0.4V_2x40_P0.4mm__J1 | Routing board reservation | TBD | TBD | TBD | TBD | RESERVATION_ONLY / ELECTRICAL REQUIREMENTS TBD | Review component ratings, pin map and circuit function before release. |  | False | True | 10.65 | 8.3 | Bottom
J2 | Routing 80-contact / proxy | TBD | TBD | Howard:Hirose_DF40C-80DS-0.4V_2x40_P0.4mm__J2 | Routing board reservation | TBD | TBD | TBD | TBD | RESERVATION_ONLY / ELECTRICAL REQUIREMENTS TBD | Review component ratings, pin map and circuit function before release. |  | False | True | 31.350001 | 8.3 | Bottom
J3 | Micro-HDMI / custom-link pinout TBD | TBD | TBD | Howard:HDMI_Micro-D_Molex_46765-1xxx__J3 | micro-HDMI reservation | TBD | TBD | TBD | TBD | RESERVATION_ONLY / ELECTRICAL REQUIREMENTS TBD | Review component ratings, pin map and circuit function before release. |  | False | True | 39.6 | 29.8 | Top
J5 | DC INPUT / 12V proposal | TBD | TBD | Howard:JST_PH_B2B-PH-K_1x02_P2.00mm_Vertical__J5 | Power input and test | TBD | TBD | TBD | TBD | Connector/input proposal; exact connector MPN, current, polarity and external supply limits TBD | Review component ratings, pin map and circuit function before release. |  | False | True | 9.5 | 35.650001 | Top
F1 | FUSE / rating TBD | TBD | TBD | Howard:Fuse_1206_3216Metric__F1 | Power input and test | TBD | TBD | TBD | TBD | Input-protection type/current/rating TBD; no reverse-polarity or surge design is implied | Review component ratings, pin map and circuit function before release. |  | False | True | 9.300001 | 30.5 | Top
C1 | 680uF | TBD | TBD | Howard:CP_EIA-7343-43_Kemet-X__C1 | FPGA decoupling | TBD | TBD | TBD | TBD | UG483 capacitor ledger proposal; ratings/MPN/effective capacitance and placement review pending | Review component ratings, pin map and circuit function before release. | https://docs.amd.com/v/u/en-US/ug483_7Series_PCB | False | True | 20.500001 | 32.600001 | Top
C2 | 4.7uF | C1005X5R1A475K050BC | TDK | Howard:C_0402_1005Metric__C2 | FPGA decoupling | 10% | 10 V | TBD | -55 to +85 C; X5R | UG483 capacitor ledger proposal; ratings/MPN/effective capacitance and placement review pending | Do not release until DC bias, temperature and FPGA PDN checks pass. | https://product.tdk.com/en/search/capacitor/ceramic/mlcc/info?part_no=C1005X5R1A475K050BC | False | True | 12.785 | 13.635 | Bottom
C3 | 4.7uF | C1005X5R1A475K050BC | TDK | Howard:C_0402_1005Metric__C3 | FPGA decoupling | 10% | 10 V | TBD | -55 to +85 C; X5R | UG483 capacitor ledger proposal; ratings/MPN/effective capacitance and placement review pending | Do not release until DC bias, temperature and FPGA PDN checks pass. | https://product.tdk.com/en/search/capacitor/ceramic/mlcc/info?part_no=C1005X5R1A475K050BC | False | True | 12.335 | 11.485 | Bottom
C4 | 4.7uF | C1005X5R1A475K050BC | TDK | Howard:C_0402_1005Metric__C4 | FPGA decoupling | 10% | 10 V | TBD | -55 to +85 C; X5R | UG483 capacitor ledger proposal; ratings/MPN/effective capacitance and placement review pending | Do not release until DC bias, temperature and FPGA PDN checks pass. | https://product.tdk.com/en/search/capacitor/ceramic/mlcc/info?part_no=C1005X5R1A475K050BC | False | True | 10.335 | 11.485 | Bottom
C5 | 4.7uF | C1005X5R1A475K050BC | TDK | Howard:C_0402_1005Metric__C5 | FPGA decoupling | 10% | 10 V | TBD | -55 to +85 C; X5R | UG483 capacitor ledger proposal; ratings/MPN/effective capacitance and placement review pending | Do not release until DC bias, temperature and FPGA PDN checks pass. | https://product.tdk.com/en/search/capacitor/ceramic/mlcc/info?part_no=C1005X5R1A475K050BC | False | True | 4.535 | 11.485 | Bottom
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

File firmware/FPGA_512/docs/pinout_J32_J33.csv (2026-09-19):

Connector | Pin | Side | Schematic_Signal | ECP5_Ball | Notes
J32 | 1 | Left | NC |  | J32 Pin 1 NC
J32 | 2 | Right | VCCIO7 |  | Power
J32 | 3 | Left | DGND |  | GND
J32 | 4 | Right | DGND |  | GND
J32 | 5 | Left | D<8> | A5
J32 | 6 | Right | NC | A4 | Unconnected in schematic
J32 | 7 | Left | DGND |  | GND
J32 | 8 | Right | DGND |  | GND
J32 | 9 | Left | D<7> | C5
J32 | 10 | Right | NC | B5 | Unconnected in schematic
J32 | 11 | Left | DGND |  | GND
J32 | 12 | Right | DGND |  | GND
J32 | 13 | Left | D<6> | B4
J32 | 14 | Right | NC | C4 | Unconnected in schematic
J32 | 15 | Left | DGND |  | GND
J32 | 16 | Right | DGND |  | GND
J32 | 17 | Left | D<5> | B3
J32 | 18 | Right | NC | A3 | Unconnected in schematic
J32 | 19 | Left | DGND |  | GND
J32 | 20 | Right | DGND |  | GND
J32 | 21 | Left | CHIP_RESET | D5
J32 | 22 | Right | CLKH | E4
J32 | 23 | Left | DGND |  | GND
J32 | 24 | Right | DGND |  | GND
J32 | 25 | Left | D<4> | D3
J32 | 26 | Right | NC | C3 | Unconnected in schematic
J32 | 27 | Left | DGND |  | GND
J32 | 28 | Right | DGND |  | GND
J32 | 29 | Left | D<1> | E3
J32 | 30 | Right | NC | F4 | Unconnected in schematic
J32 | 31 | Left | DGND |  | GND
J32 | 32 | Right | DGND |  | GND
J32 | 33 | Left | D<2> | F5
J32 | 34 | Right | NC | E5 | Unconnected in schematic
J32 | 35 | Left | DGND |  | GND
J32 | 36 | Right | DGND |  | GND
J32 | 37 | Left | D<3> | B1
J32 | 38 | Right | NC | A2 | Unconnected in schematic
J32 | 39 | Left | DGND |  | GND
J32 | 40 | Right | DGND |  | GND
J33 | 1 | Left | NC |  | J33 Pin 1 NC
J33 | 2 | Right | VCCIO7 |  | Power
J33 | 3 | Left | DGND |  | GND
J33 | 4 | Right | DGND |  | GND
J33 | 5 | Left | AC_IN | C2
J33 | 6 | Right | IMP_TEST | B2
J33 | 7 | Left | DGND |  | GND
J33 | 8 | Right | DGND |  | GND
J33 | 9 | Left | FE_RESET | D1
J33 | 10 | Right | SPI_CLK | C1
J33 | 11 | Left | DGND |  | GND
J33 | 12 | Right | DGND |  | GND
J33 | 13 | Left | SPI_LATCH | E1
J33 | 14 | Right | CLK32MHZ | D2
J33 | 15 | Left | DGND |  | GND
J33 | 16 | Right | DGND |  | GND
J33 | 17 | Left | SPI_DINR | G5
J33 | 18 | Right | READ | H4
J33 | 19 | Left | DGND |  | GND
J33 | 20 | Right | DGND |  | GND
J33 | 21 | Left | SPI_DINL | H3
J33 | 22 | Right | SYNC | H5
J33 | 23 | Left | DGND |  | GND
J33 | 24 | Right | DGND |  | GND
J33 | 25 | Left | STIM_EN | F3
J33 | 26 | Right | STIM_CHB | G3
J33 | 27 | Left | DGND |  | GND
J33 | 28 | Right | DGND |  | GND
J33 | 29 | Left | STIM_START | E2
J33 | 30 | Right | STIM_CLK | F2
J33 | 31 | Left | DGND |  | GND
J33 | 32 | Right | DGND |  | GND

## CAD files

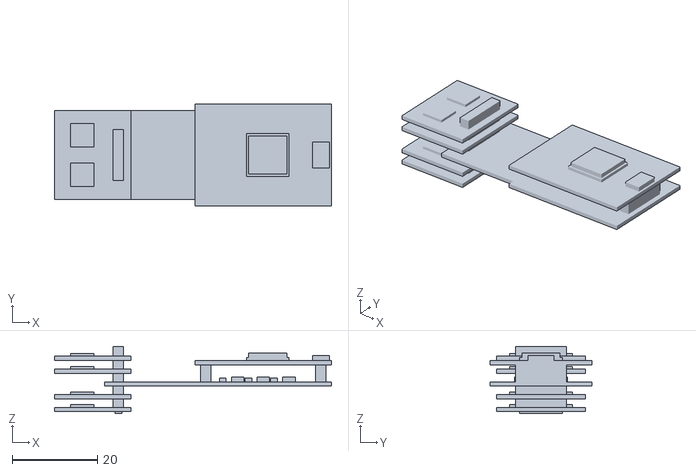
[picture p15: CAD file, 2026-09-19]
hardware/assembly/stacked_headboard_original.stl
65.0 x 24.0 x 15.8

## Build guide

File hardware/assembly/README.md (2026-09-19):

# Overall 3D assembly concept

This is the original stacked-headboard model previously supplied and reviewed for the project. The STL is included unchanged, together with the earlier labeled preview.

Overall assembly concept with regions A, B, C and D

**[Open the 3D STL](stacked_headboard_original.stl)** · **[Download the STL](stacked_headboard_original.stl?raw=true)** · [Full-size labeled image](stacked_headboard_labeled.png)

GitHub supports rotating STL previews. If the preview does not load, download the file and open it in an STL-capable CAD or mesh viewer.

## Reading the assembly

The following roles were confirmed during the earlier model discussion; the STL itself stores geometry, not electrical roles or part names.

| Region | Project role |
|---|---|
| A | Stack of four ASIC carrier boards, with two ASICs per board in the discussed arrangement |
| B + C | Routing PCB: connecting section and lower board region |
| D | FPGA PCB above the routing-board region |

The model depicts the headboard assembly portion of the project. The downstream KR260, PC and external cabling are outside this model; see the [system diagram](../overview.md#where-the-boards-fit).

## Version and limits

This is the **original supplied model**, originally named `stacked_headboard_onebody (1).stl`. The separately generated shortened-bridge variant is not included here. The original author's identity has not been verified, so this file is not attributed to Gerald.

The mesh has 650 triangles and an envelope of **65 × 24 × 15.75 model units**. STL does not encode units, and the earlier discussion treated dimensions as provisional. These numbers must not be assumed to be millimeters or final board dimensions.

Use it to understand the arrangement. It is not a detailed electrical assembly, a confirmed mechanical fit, or evidence that the two [supplied reference PCB designs](../README.md) mate exactly as shown. The block geometry does not specify an FPGA part number, connector mapping, component clearances or manufacturing tolerances.

[Source provenance](../../sources/README.md) and the [manifest](../../sources/manifest.json) record the original filename and checksums. The preview is an existing rendered representation; the underlying STL bytes are preserved.

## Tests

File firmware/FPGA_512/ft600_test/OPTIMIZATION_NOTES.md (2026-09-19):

# FT600 Throughput Optimization Notes

## Current Status
- **Data integrity: PASS** — zero errors with settle-after-accept writer
- **Throughput: 0.028 MB/s** — far below theoretical ~35 MB/s (USB 2.0 HS)
- The settle cycle (pause 1 clock after each accepted write) kills throughput

## Root Cause of All Errors
The async FIFO uses non-blocking pointer advance (`rptr_bin <= rptr_bin + 1`).
When `fifo_ren=1` and `data_out <= fifo_rdata` happen on the **same clock edge**,
`fifo_rdata` still shows the **old** word (pre-advance) because non-blocking
assignments evaluate RHS with pre-edge values.

This means: every time we advance the FIFO and sample rdata simultaneously,
we get the word we just consumed, not the next word.

## Approaches Tried

### 1. Direct combinational (first attempt)
```verilog
wire can_send = ~txe_n & ~fifo_empty;
assign fifo_ren = can_send;
data_out <= fifo_rdata;  // stale on advance edges
```
**Result:** ~2000 errors per 10 MB. 1 word skipped at irregular intervals (~1500 words).
Skips happen because fifo_ren advances the pointer, but data_out gets stale rdata.
The FT600 captures stale data, then the next fresh word is 1 ahead → skip.

### 2. Registered TXE_N (`txe_n_r`)
```verilog
reg txe_n_r;
always @(posedge clk) txe_n_r <= txe_n;
if (!txe_n_r) begin wr_n <= 0; ... end
```
**Result:** 2 words skipped per 2048 words (4KB FT600 buffer boundary).
The 1-cycle TXE_N delay means 1 extra write after buffer full + 1 from the
pipeline. Counter increments for both but FT600 doesn't capture.

### 3. Mixed registered + live TXE_N
```verilog
wire can_write = ~txe_n_r;      // drive decision on registered
wire write_ok  = can_write & ~txe_n;  // counter advance on both
```
**Result:** 1 word skipped per 2048 words. Improved from 2 to 1 skip.

### 4. Live TXE_N only (no register)
```verilog
if (!txe_n) begin wr_n <= 0; data_out <= counter; counter <= counter + 1; end
```
**Result:** 1 word skipped per 2048 words. Same as #3 — the skip is from the
registered WR_N pipeline, not the TXE_N sampling.

### 5. Holding register with `accepted` signal
```verilog
wire accepted = ~wr_n & ~txe_n;
assign fifo_ren = accepted;
// Various holding register strategies
```
**Result:** Duplicates instead of skips. The holding register re-drives the
consumed word because fifo_rdata is stale on the advance edge.

### 6. State machine (IDLE → PREFETCH → WRITE)
**Result:** Both skips AND duplicates. More complex, more bugs, worse.

### 7. Two-phase (LATCH → DRIVE with fifo_ren in DRIVE)
```verilog
assign fifo_ren = phase & ~txe_n & ~fifo_empty;  // advance in DRIVE
// LATCH: word <= fifo_rdata
// DRIVE: data_out <= word, fifo_ren fires
```
**Result:** Every other word skipped (0x0001, 0x0003, 0x0005...).
fifo_ren is a reg, so its value persists into the LATCH cycle causing
a spurious advance.

### 8. Settle-after-accept
```verilog
wire accepted = ~wr_n & ~txe_n;
assign fifo_ren = accepted;  // advance only on confirmed capture

if (accepted)
    wr_n <= 1;  // pause 1 cycle for pointer to settle
else if (~fifo_empty & ~txe_n)
    data_out <= fifo_rdata;  // safe: pointer is stable
```
**Result:** ZERO errors in direct-counter mode. Throughput = 0.028 MB/s — the
settle cycle halves FIFO utilization AND interacts badly with the FT600's
buffering, causing far worse throughput than expected. Re-tested with the async
FIFO after USB path fixes: still very slow (~0.03 MB/s range), and **same
duplicate errors** as approach #10 (~5–7 per 10 MB). The settle cycle does NOT
fix the underlying CDC issue and kills throughput. Do not use.

### 9. Confirmed-accept with counter bypass (CURRENT — ft600_streamer.v, WORKING)
```verilog
wire accepted = ~wr_n & ~txe_n;
data_out <= accepted ? (counter + 1) : counter;
if (accepted) counter <= counter + 1;
```
**Result:** ZERO errors, 35 MB/s (USB 2.0). Counter only advances on confirmed
capture. Combinational bypass (`counter + 1`) keeps the pipeline full with no
settle cycle. Eliminates the 1-skip-per-2048 boundary error completely.

### 10. Look-ahead bypass with async FIFO (CURRENT — ft600_writer.v, ~4–7 dupes/10 MB)
```verilog
wire accepted = ~wr_n & ~txe_n;
assign fifo_ren = accepted;
data_out <= accepted ? fifo_rdata_next : fifo_rdata;
// fifo_rdata_next = mem[rptr_bin + 1]  (added to async_fifo.v)
// almost_empty guard prevents reading invalid rdata_next on last word
```
**Result:** ~22 MB/s throughput, but 4–7 duplicate errors per 10 MB.
All errors are `got = expected - 1` (duplicates, not skips). The settle-after-
accept approach (#8) produces the **identical error pattern**, proving this is
NOT a timing/combinational-path issue in the look-ahead MUX. The root cause
is in the async FIFO's CDC read path — see "Open Issue" below.

## Key Lessons

### Verilog / FPGA
1. **Non-blocking assignments** mean `fifo_rdata` is stale on the same edge as `fifo_ren`.
   You CANNOT advance and sample in the same cycle.
2. **Combinational wires vs registered signals**: `fifo_ren` as a wire (`assign`) fires
   immediately; as a `reg` it persists into the next cycle causing spurious advances.
3. **The FTDI reference design** avoids this by using a LOCAL RAM with INDEPENDENT
   read and memory-enable signals. `adv_c_rptr` (pointer advance) and `mem_rden`
   (memory read) are separate. The pointer only advances when TXE_N is confirmed low.
   The memory always shows data at the current pointer. No stale data issue because
   the RAM output is combinational from a pointer that only advances on confirmed writes.
4. **IO_TYPE must match VCCIO**: Bank 2 = 1.5V → LVCMOS15, Banks 6/7 = 2.5V → LVCMOS25.
   Wrong IO_TYPE causes input threshold failures (signals unreadable).
5. **FT600 requires `FT_SetStreamPipe`** from host before TXE_N asserts low.
   Without it, the FIFO bus stays idle.

### C / Host Side
1. **`FT_ReadPipe` works on macOS**, not `FT_ReadPipeEx` (returns FT_INVALID_PARAMETER).
2. **`FT_SetStreamPipe(handle, FALSE, FALSE, 0x82, chunk_size)`** must be called before
   any reads. This activates TXE_N on the FIFO bus.
3. **`FT_Create` requires the FTDI D3XX driver .dmg** installed on macOS. Without it,
   returns FT_DEVICE_NOT_OPENED (status 3). PyD3XX's bundled dylib alone is not enough.
4. **D3XX library version**: `/usr/local/lib/libftd3xx.dylib` from the FTDI .dmg.
   Must allow in System Settings → Privacy & Security after first run.
5. **USB cable must be data-capable** (not charge-only).
6. **Unplug/replug USB after reflashing** FPGA — FT600 state is stale after JTAG flash.

## Resolved: Async FIFO CDC Duplicates

The async FIFO path (32 MHz write → 100 MHz read) was producing ~5
duplicate words per 10 MB. Root cause: combinational reads from dual-clock
distributed RAM (LUT-based). Yosys couldn't infer Block RAM because the
original design used `assign rdata = mem[rptr_bin[AW-1:0]]` (combinational),
which doesn't map to ECP5 DP16KD (requires registered reads).

### 11. Block RAM + output buffer (CURRENT — async_fifo.v)
```verilog
(* ram_style = "block" *)
reg [W-1:0] mem [0:D-1];
always @(posedge rclk) mem_rdata <= mem[iptr_bin[AW-1:0]];  // registered read → DP16KD

// 4-entry output buffer hides 1-cycle BRAM latency
// Pre-fetch FSM fills ob[] whenever FIFO has data and ob has room
// External interface (rdata, rdata_next, empty, almost_empty) unchanged
assign rdata      = ob[ob_rptr[1:0]];       // combinational from registers
assign rdata_next = ob[ob_rptr[1:0] + 1];   // safe: single clock domain
```
**Architecture:** registered BRAM read (1-cycle latency) → pre-fetch pipeline
→ 4-entry register-based output buffer with combinational outputs. The
output buffer is entirely in the rclk domain — no CDC on the data path.

**Yosys workaround:** Default `synth_ecp5` runs `opt -undriven` which
incorrectly removes DP16KD cells. The Makefile uses a split synthesis flow:
`synth_ecp5 -run :map_ffram` (stops before the bad opt), manual `opt`
without `-undriven`, then `synth_ecp5 -run map_gates:` to finish.

**Result:** 4× DP16KD inferred, all clocks pass timing, 74% LUT utilization.
ft600_writer.v and top_custom.v unchanged — same interface.

**Previous "ruled out" note was wrong:** Block RAM alone forces a settle
cycle (killing throughput to 0.028 MB/s), but Block RAM + output buffer
provides combinational outputs with zero settle cycles. The pre-fetch
pipeline sustains 1 word/cycle after 1-cycle startup.

## Integrated System Results (2026-07-14)

Full ADC pipeline running: ADC board → rx_process_mux → lane_framer →
bit_packer (4 serial bits × 4 time-steps = 16-bit word) → async_fifo
(16 MHz write → 100 MHz read) → ft600_writer → USB → host decode.

- **Throughput:** 8 MB/s (16 MHz clock / 4 = 4 MW/s × 2 bytes)
- **Frames decoded:** 815 per lane per 1 MB capture
- **CRC errors:** 9–38 per 1 MB across 3 trials (variable)
- **Error amplification:** each CDC glitch corrupts a 16-bit packed word
  containing 16 serial bits across all 4 lanes. One FIFO glitch can
  cause up to 4 CRC failures (one per lane per affected frame).
- **Estimated CDC events:** 2–10 per MB, worse than the counter test
  (~0.5/MB) because the FIFO is mostly empty at 4 MW/s write rate,
  keeping rptr close to wptr and increasing read-write collision odds.

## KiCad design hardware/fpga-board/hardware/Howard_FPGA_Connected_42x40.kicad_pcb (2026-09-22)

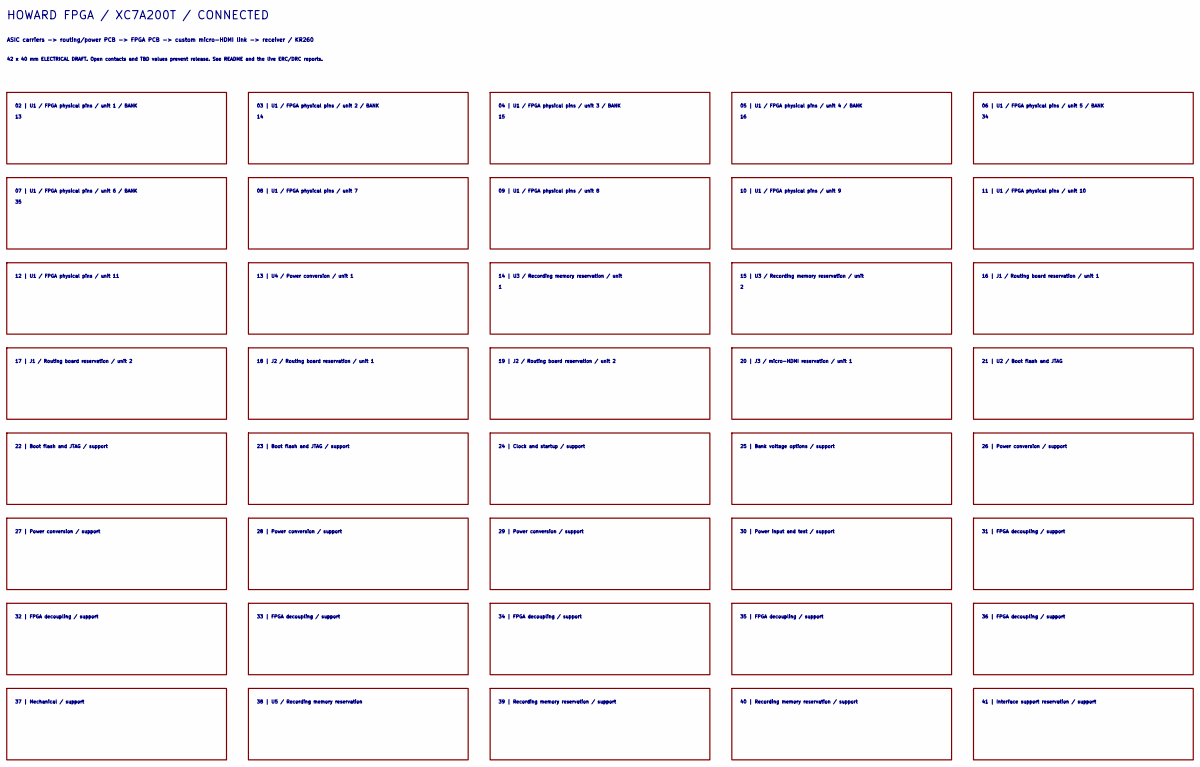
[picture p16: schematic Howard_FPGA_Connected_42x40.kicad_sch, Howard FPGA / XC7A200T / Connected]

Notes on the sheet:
22 | Boot flash and JTAG / support
17 | J1 / Routing board reservation / unit 2
30 | Power input and test / support
23 | Boot flash and JTAG / support
ASIC carriers -> routing/power PCB -> FPGA PCB -> custom micro-HDMI link -> receiver / KR260
03 | U1 / FPGA physical pins / unit 2 / BANK
05 | U1 / FPGA physical pins / unit 4 / BANK
18 | J2 / Routing board reservation / unit 1
31 | FPGA decoupling / support
06 | U1 / FPGA physical pins / unit 5 / BANK
35 | FPGA decoupling / support
32 | FPGA decoupling / support
34 | FPGA decoupling / support
04 | U1 / FPGA physical pins / unit 3 / BANK
21 | U2 / Boot flash and JTAG
11 | U1 / FPGA physical pins / unit 10
26 | Power conversion / support
09 | U1 / FPGA physical pins / unit 8
13 | U4 / Power conversion / unit 1
37 | Mechanical / support
33 | FPGA decoupling / support
24 | Clock and startup / support
HOWARD FPGA / XC7A200T / CONNECTED
28 | Power conversion / support
07 | U1 / FPGA physical pins / unit 6 / BANK
25 | Bank voltage options / support
16 | J1 / Routing board reservation / unit 1
36 | FPGA decoupling / support
42 x 40 mm ELECTRICAL DRAFT. Open contacts and TBD values prevent release. See README and the live ERC/DRC reports.
40 | Recording memory reservation / support
15 | U3 / Recording memory reservation / unit
08 | U1 / FPGA physical pins / unit 7
02 | U1 / FPGA physical pins / unit 1 / BANK
10 | U1 / FPGA physical pins / unit 9
41 | Interface support reservation / support
39 | Recording memory reservation / support
29 | Power conversion / support
27 | Power conversion / support
19 | J2 / Routing board reservation / unit 2
12 | U1 / FPGA physical pins / unit 11

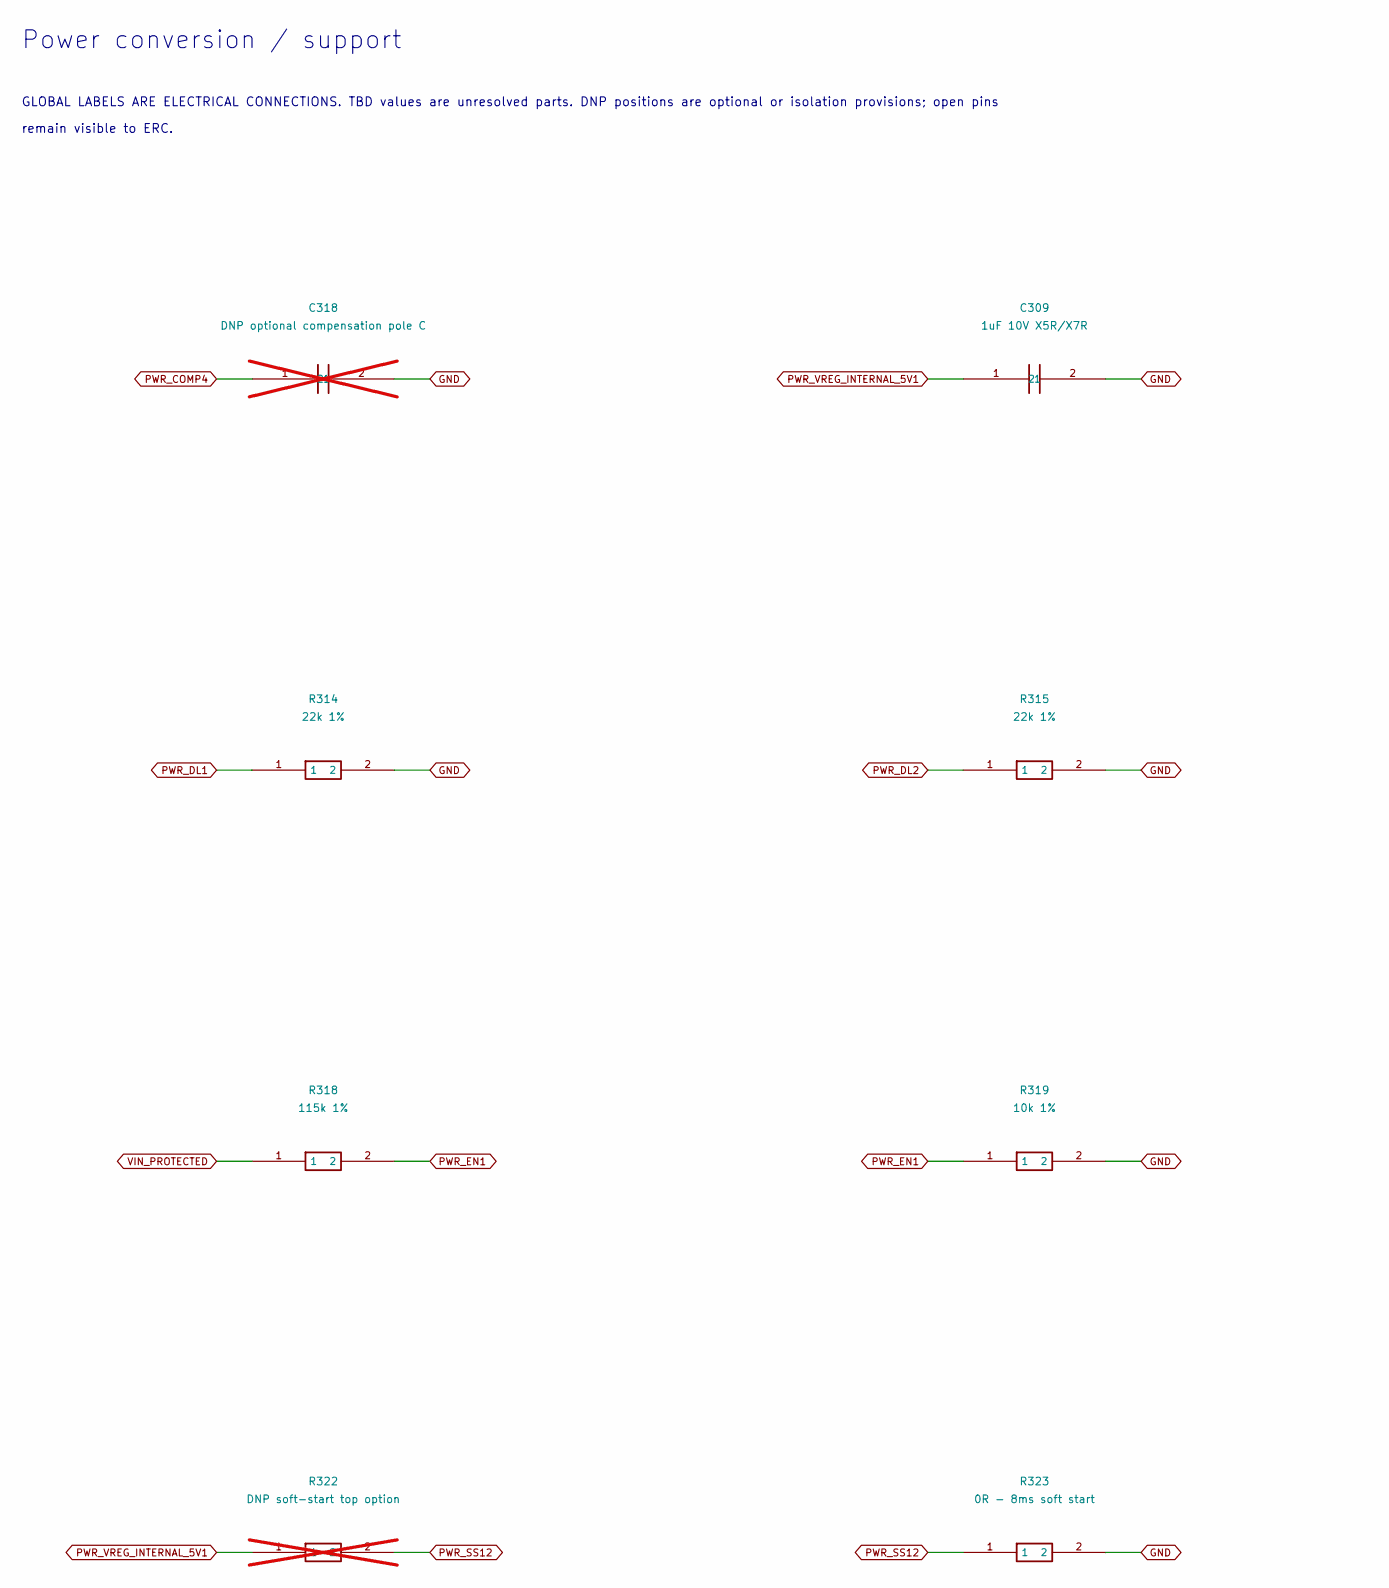
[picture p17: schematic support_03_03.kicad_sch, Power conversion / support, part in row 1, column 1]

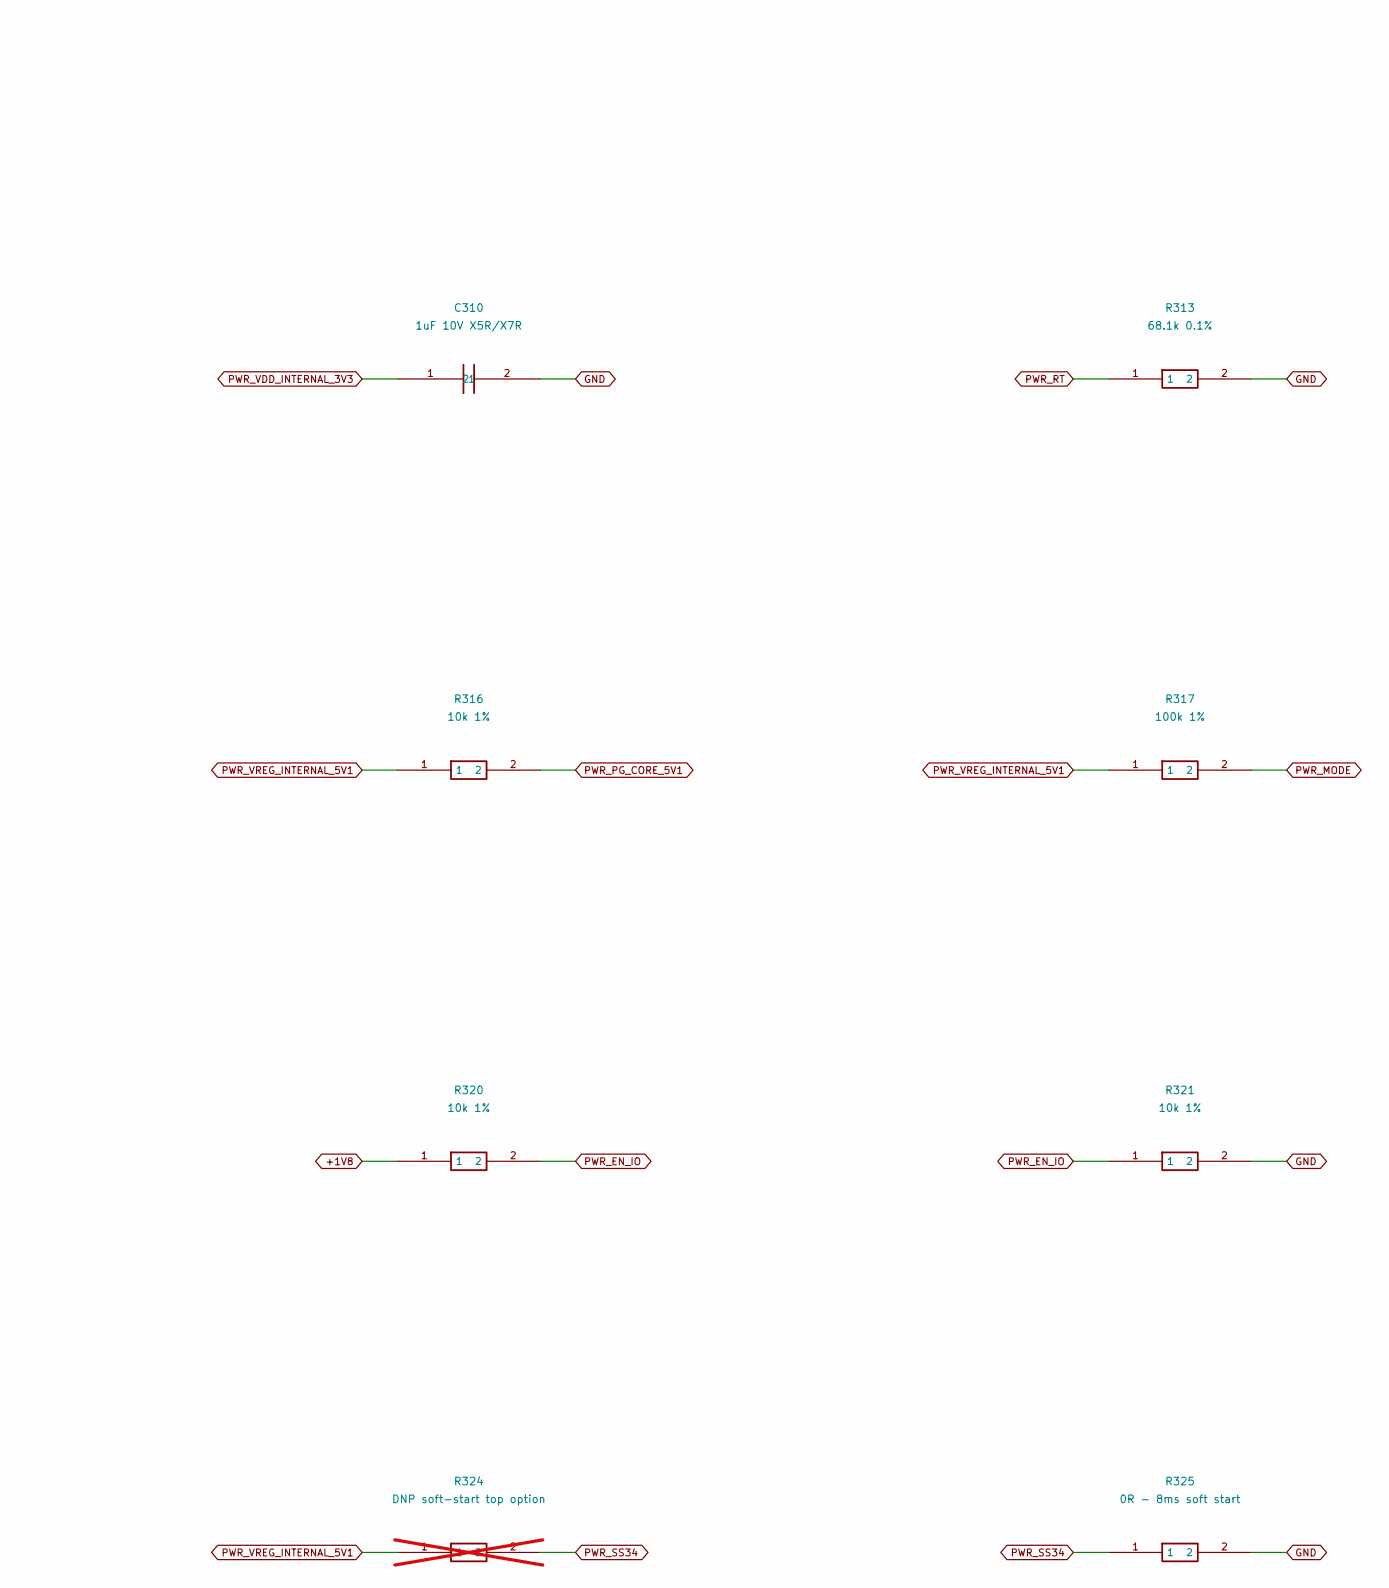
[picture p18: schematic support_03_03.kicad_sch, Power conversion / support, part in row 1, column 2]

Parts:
C309: 1uF 10V X5R/X7R; C_0402_1005Metric__C309; Tolerance TBD; Voltage rating TBD; MPN TBD
C310: 1uF 10V X5R/X7R; C_0402_1005Metric__C310; Tolerance TBD; Voltage rating TBD; MPN TBD
C318: DNP optional compensation pole C; C_0402_1005Metric__C318; Tolerance TBD; Voltage rating TBD; MPN TBD; not fitted
R313: 68.1k 0.1%; R_0402_1005Metric__R313; Tolerance TBD; Voltage rating TBD; MPN TBD
R314: 22k 1%; R_0402_1005Metric__R314; Tolerance TBD; Voltage rating TBD; MPN TBD
R315: 22k 1%; R_0402_1005Metric__R315; Tolerance TBD; Voltage rating TBD; MPN TBD
R316: 10k 1%; R_0402_1005Metric__R316; Tolerance TBD; Voltage rating TBD; MPN TBD
R317: 100k 1%; R_0402_1005Metric__R317; Tolerance TBD; Voltage rating TBD; MPN TBD
R318: 115k 1%; R_0402_1005Metric__R318; Tolerance TBD; Voltage rating TBD; MPN TBD
R319: 10k 1%; R_0402_1005Metric__R319; Tolerance TBD; Voltage rating TBD; MPN TBD
R320: 10k 1%; R_0402_1005Metric__R320; Tolerance TBD; Voltage rating TBD; MPN TBD
R321: 10k 1%; R_0402_1005Metric__R321; Tolerance TBD; Voltage rating TBD; MPN TBD
R322: DNP soft-start top option; R_0402_1005Metric__R322; Tolerance TBD; Voltage rating TBD; MPN TBD; not fitted
R323: 0R - 8ms soft start; R_0402_1005Metric__R323; Tolerance TBD; Voltage rating TBD; MPN TBD
R324: DNP soft-start top option; R_0402_1005Metric__R324; Tolerance TBD; Voltage rating TBD; MPN TBD; not fitted
R325: 0R - 8ms soft start; R_0402_1005Metric__R325; Tolerance TBD; Voltage rating TBD; MPN TBD

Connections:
+1V8: R320.1; also elsewhere on the board
GND: C309.2, C310.2, C318.2, R313.2, R314.2, R315.2, R319.2, R321.2, R323.2, R325.2; also elsewhere on the board
PWR_COMP4: C318.1; also elsewhere on the board
PWR_DL1: R314.1; also elsewhere on the board
PWR_DL2: R315.1; also elsewhere on the board
PWR_EN1: R318.2, R319.1; also elsewhere on the board
PWR_EN_IO: R320.2, R321.1; also elsewhere on the board
PWR_MODE: R317.2; also elsewhere on the board
PWR_PG_CORE_5V1: R316.2; also elsewhere on the board
PWR_RT: R313.1; also elsewhere on the board
PWR_SS12: R322.2, R323.1; also elsewhere on the board
PWR_SS34: R324.2, R325.1; also elsewhere on the board
PWR_VDD_INTERNAL_3V3: C310.1; also elsewhere on the board
PWR_VREG_INTERNAL_5V1: C309.1, R316.1, R317.1, R322.1, R324.1; also elsewhere on the board
VIN_PROTECTED: R318.1; also elsewhere on the board

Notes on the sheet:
GLOBAL LABELS ARE ELECTRICAL CONNECTIONS. TBD values are unresolved parts. DNP positions are optional or isolation provisions; open pins
Power conversion / support
remain visible to ERC.

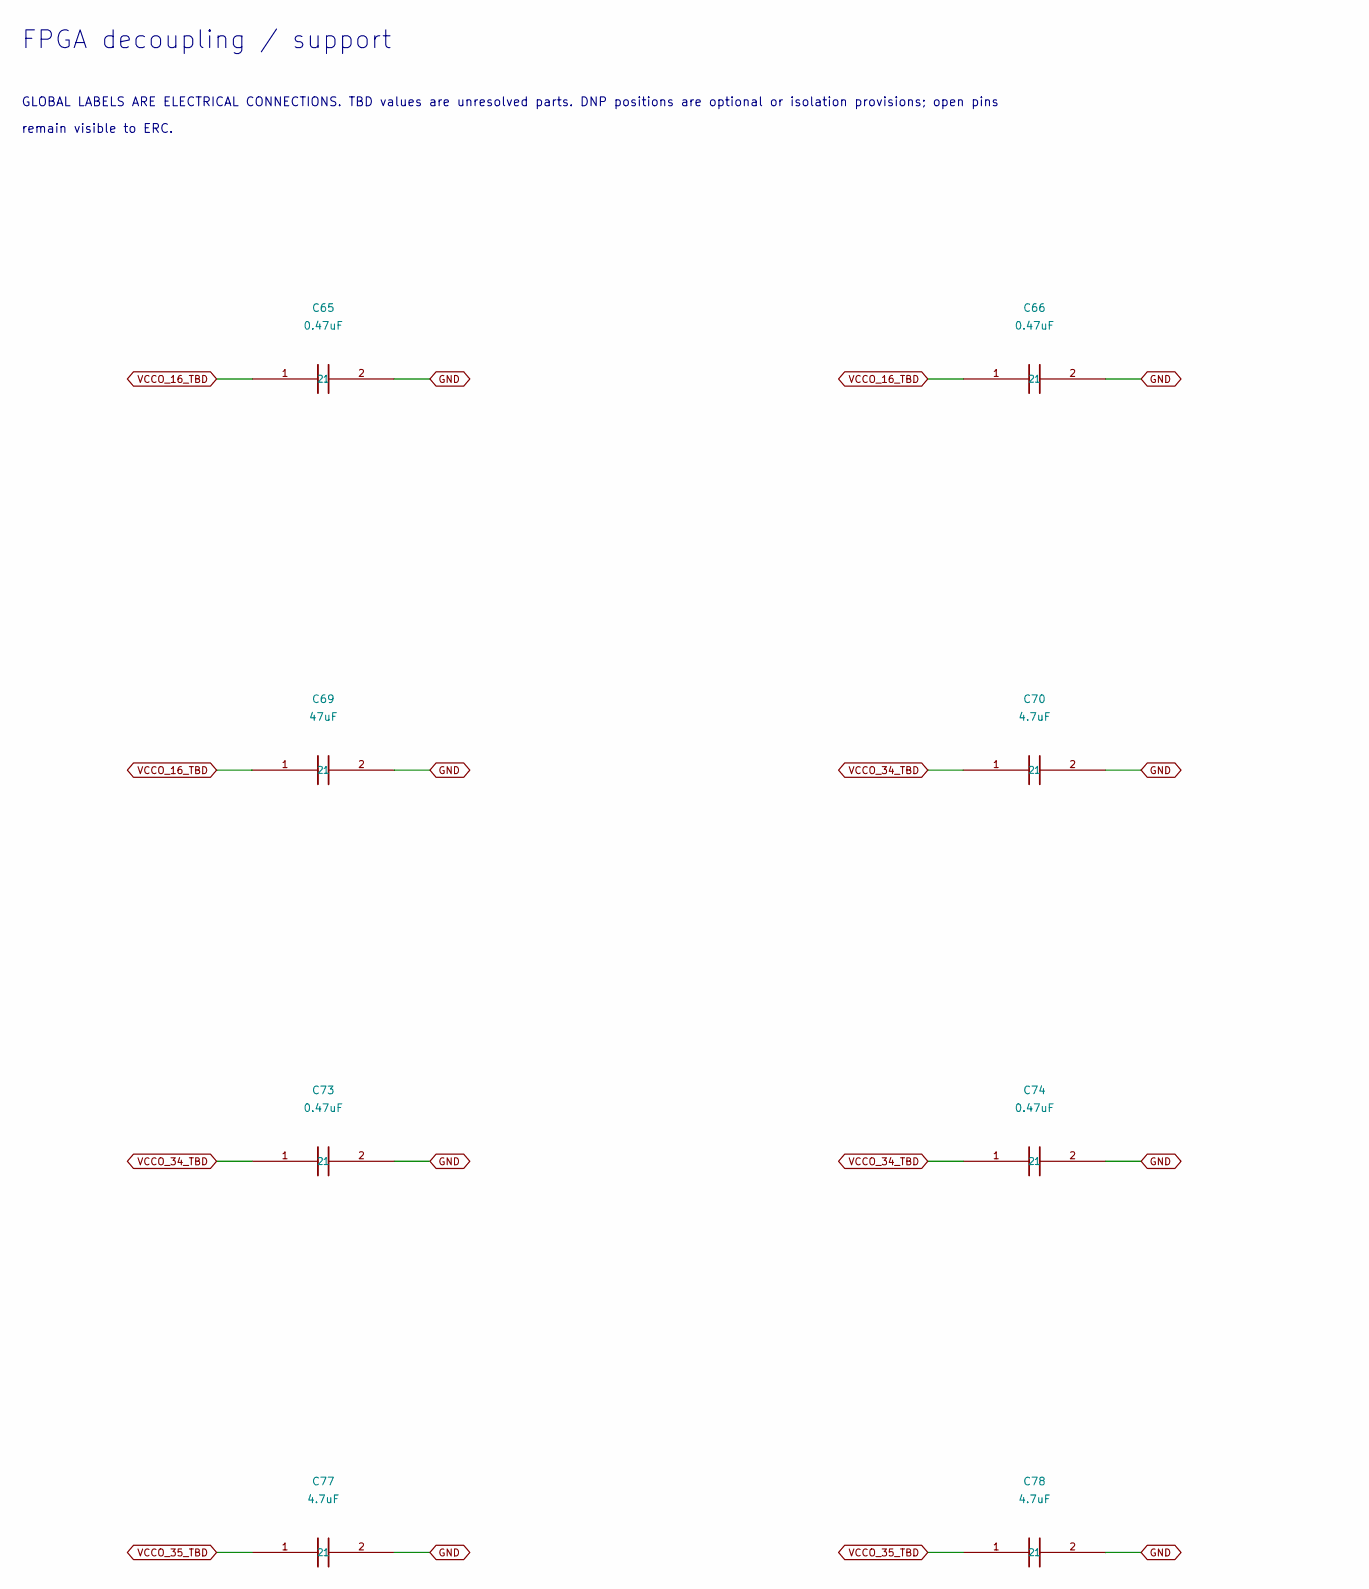
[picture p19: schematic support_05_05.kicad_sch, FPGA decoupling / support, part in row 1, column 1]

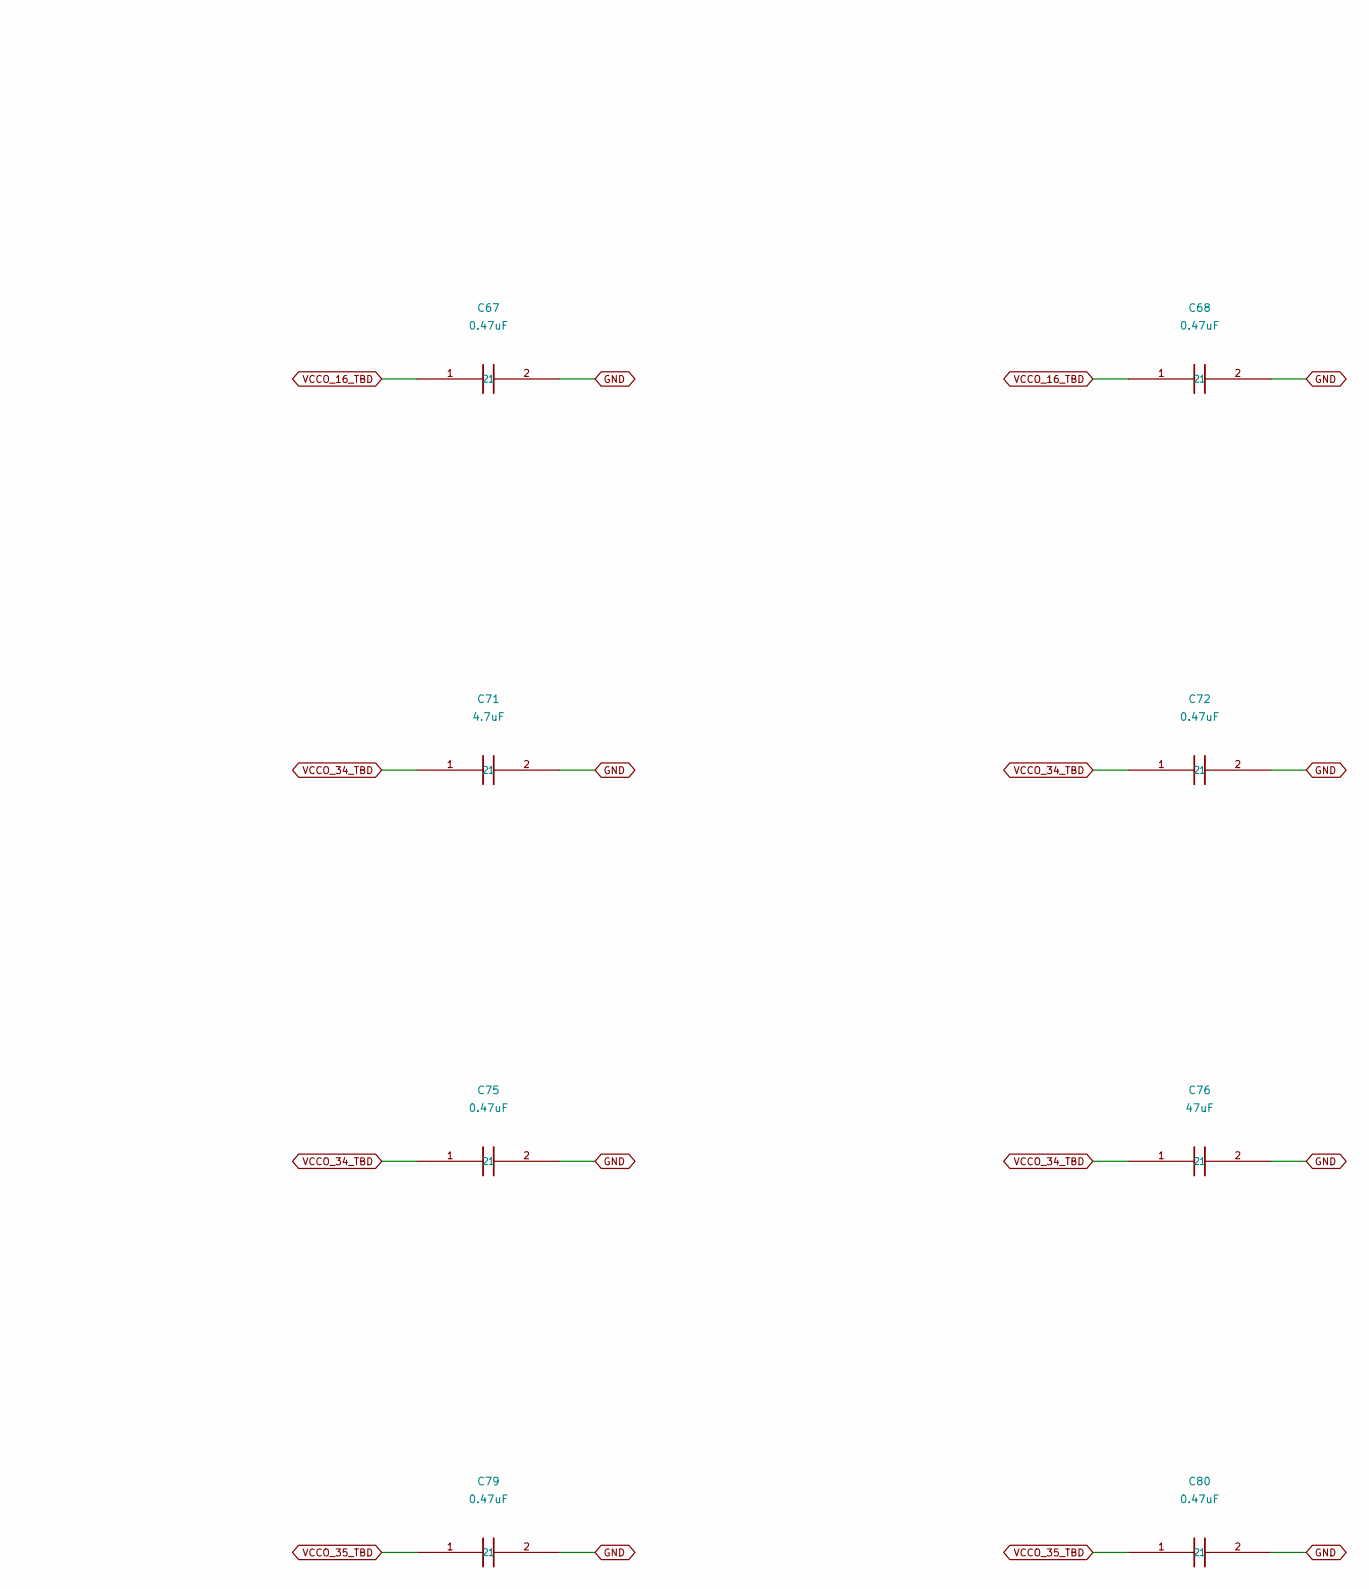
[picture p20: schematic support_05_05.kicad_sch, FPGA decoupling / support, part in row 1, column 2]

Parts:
C65: 0.47uF; C_0201_0603Metric__C65; Tolerance 20%; Voltage rating 10 V; MPN C0603X5R1A474M030BC
C66: 0.47uF; C_0201_0603Metric__C66; Tolerance 20%; Voltage rating 10 V; MPN C0603X5R1A474M030BC
C67: 0.47uF; C_0201_0603Metric__C67; Tolerance 20%; Voltage rating 10 V; MPN C0603X5R1A474M030BC
C68: 0.47uF; C_0201_0603Metric__C68; Tolerance 20%; Voltage rating 10 V; MPN C0603X5R1A474M030BC
C69: 47uF; C_1210_3225Metric__C69; Tolerance TBD; Voltage rating TBD; MPN TBD
C70: 4.7uF; C_0402_1005Metric__C70; Tolerance 10%; Voltage rating 10 V; MPN C1005X5R1A475K050BC
C71: 4.7uF; C_0402_1005Metric__C71; Tolerance 10%; Voltage rating 10 V; MPN C1005X5R1A475K050BC
C72: 0.47uF; C_0201_0603Metric__C72; Tolerance 20%; Voltage rating 10 V; MPN C0603X5R1A474M030BC
C73: 0.47uF; C_0201_0603Metric__C73; Tolerance 20%; Voltage rating 10 V; MPN C0603X5R1A474M030BC
C74: 0.47uF; C_0201_0603Metric__C74; Tolerance 20%; Voltage rating 10 V; MPN C0603X5R1A474M030BC
C75: 0.47uF; C_0201_0603Metric__C75; Tolerance 20%; Voltage rating 10 V; MPN C0603X5R1A474M030BC
C76: 47uF; C_1210_3225Metric__C76; Tolerance TBD; Voltage rating TBD; MPN TBD
C77: 4.7uF; C_0402_1005Metric__C77; Tolerance 10%; Voltage rating 10 V; MPN C1005X5R1A475K050BC
C78: 4.7uF; C_0402_1005Metric__C78; Tolerance 10%; Voltage rating 10 V; MPN C1005X5R1A475K050BC
C79: 0.47uF; C_0201_0603Metric__C79; Tolerance 20%; Voltage rating 10 V; MPN C0603X5R1A474M030BC
C80: 0.47uF; C_0201_0603Metric__C80; Tolerance 20%; Voltage rating 10 V; MPN C0603X5R1A474M030BC

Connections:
GND: C65.2, C66.2, C67.2, C68.2, C69.2, C70.2, C71.2, C72.2, C73.2, C74.2, C75.2, C76.2, C77.2, C78.2, C79.2, C80.2; also elsewhere on the board
VCCO_16_TBD: C65.1, C66.1, C67.1, C68.1, C69.1; also elsewhere on the board
VCCO_34_TBD: C70.1, C71.1, C72.1, C73.1, C74.1, C75.1, C76.1; also elsewhere on the board
VCCO_35_TBD: C77.1, C78.1, C79.1, C80.1; also elsewhere on the board

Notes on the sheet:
GLOBAL LABELS ARE ELECTRICAL CONNECTIONS. TBD values are unresolved parts. DNP positions are optional or isolation provisions; open pins
FPGA decoupling / support
remain visible to ERC.

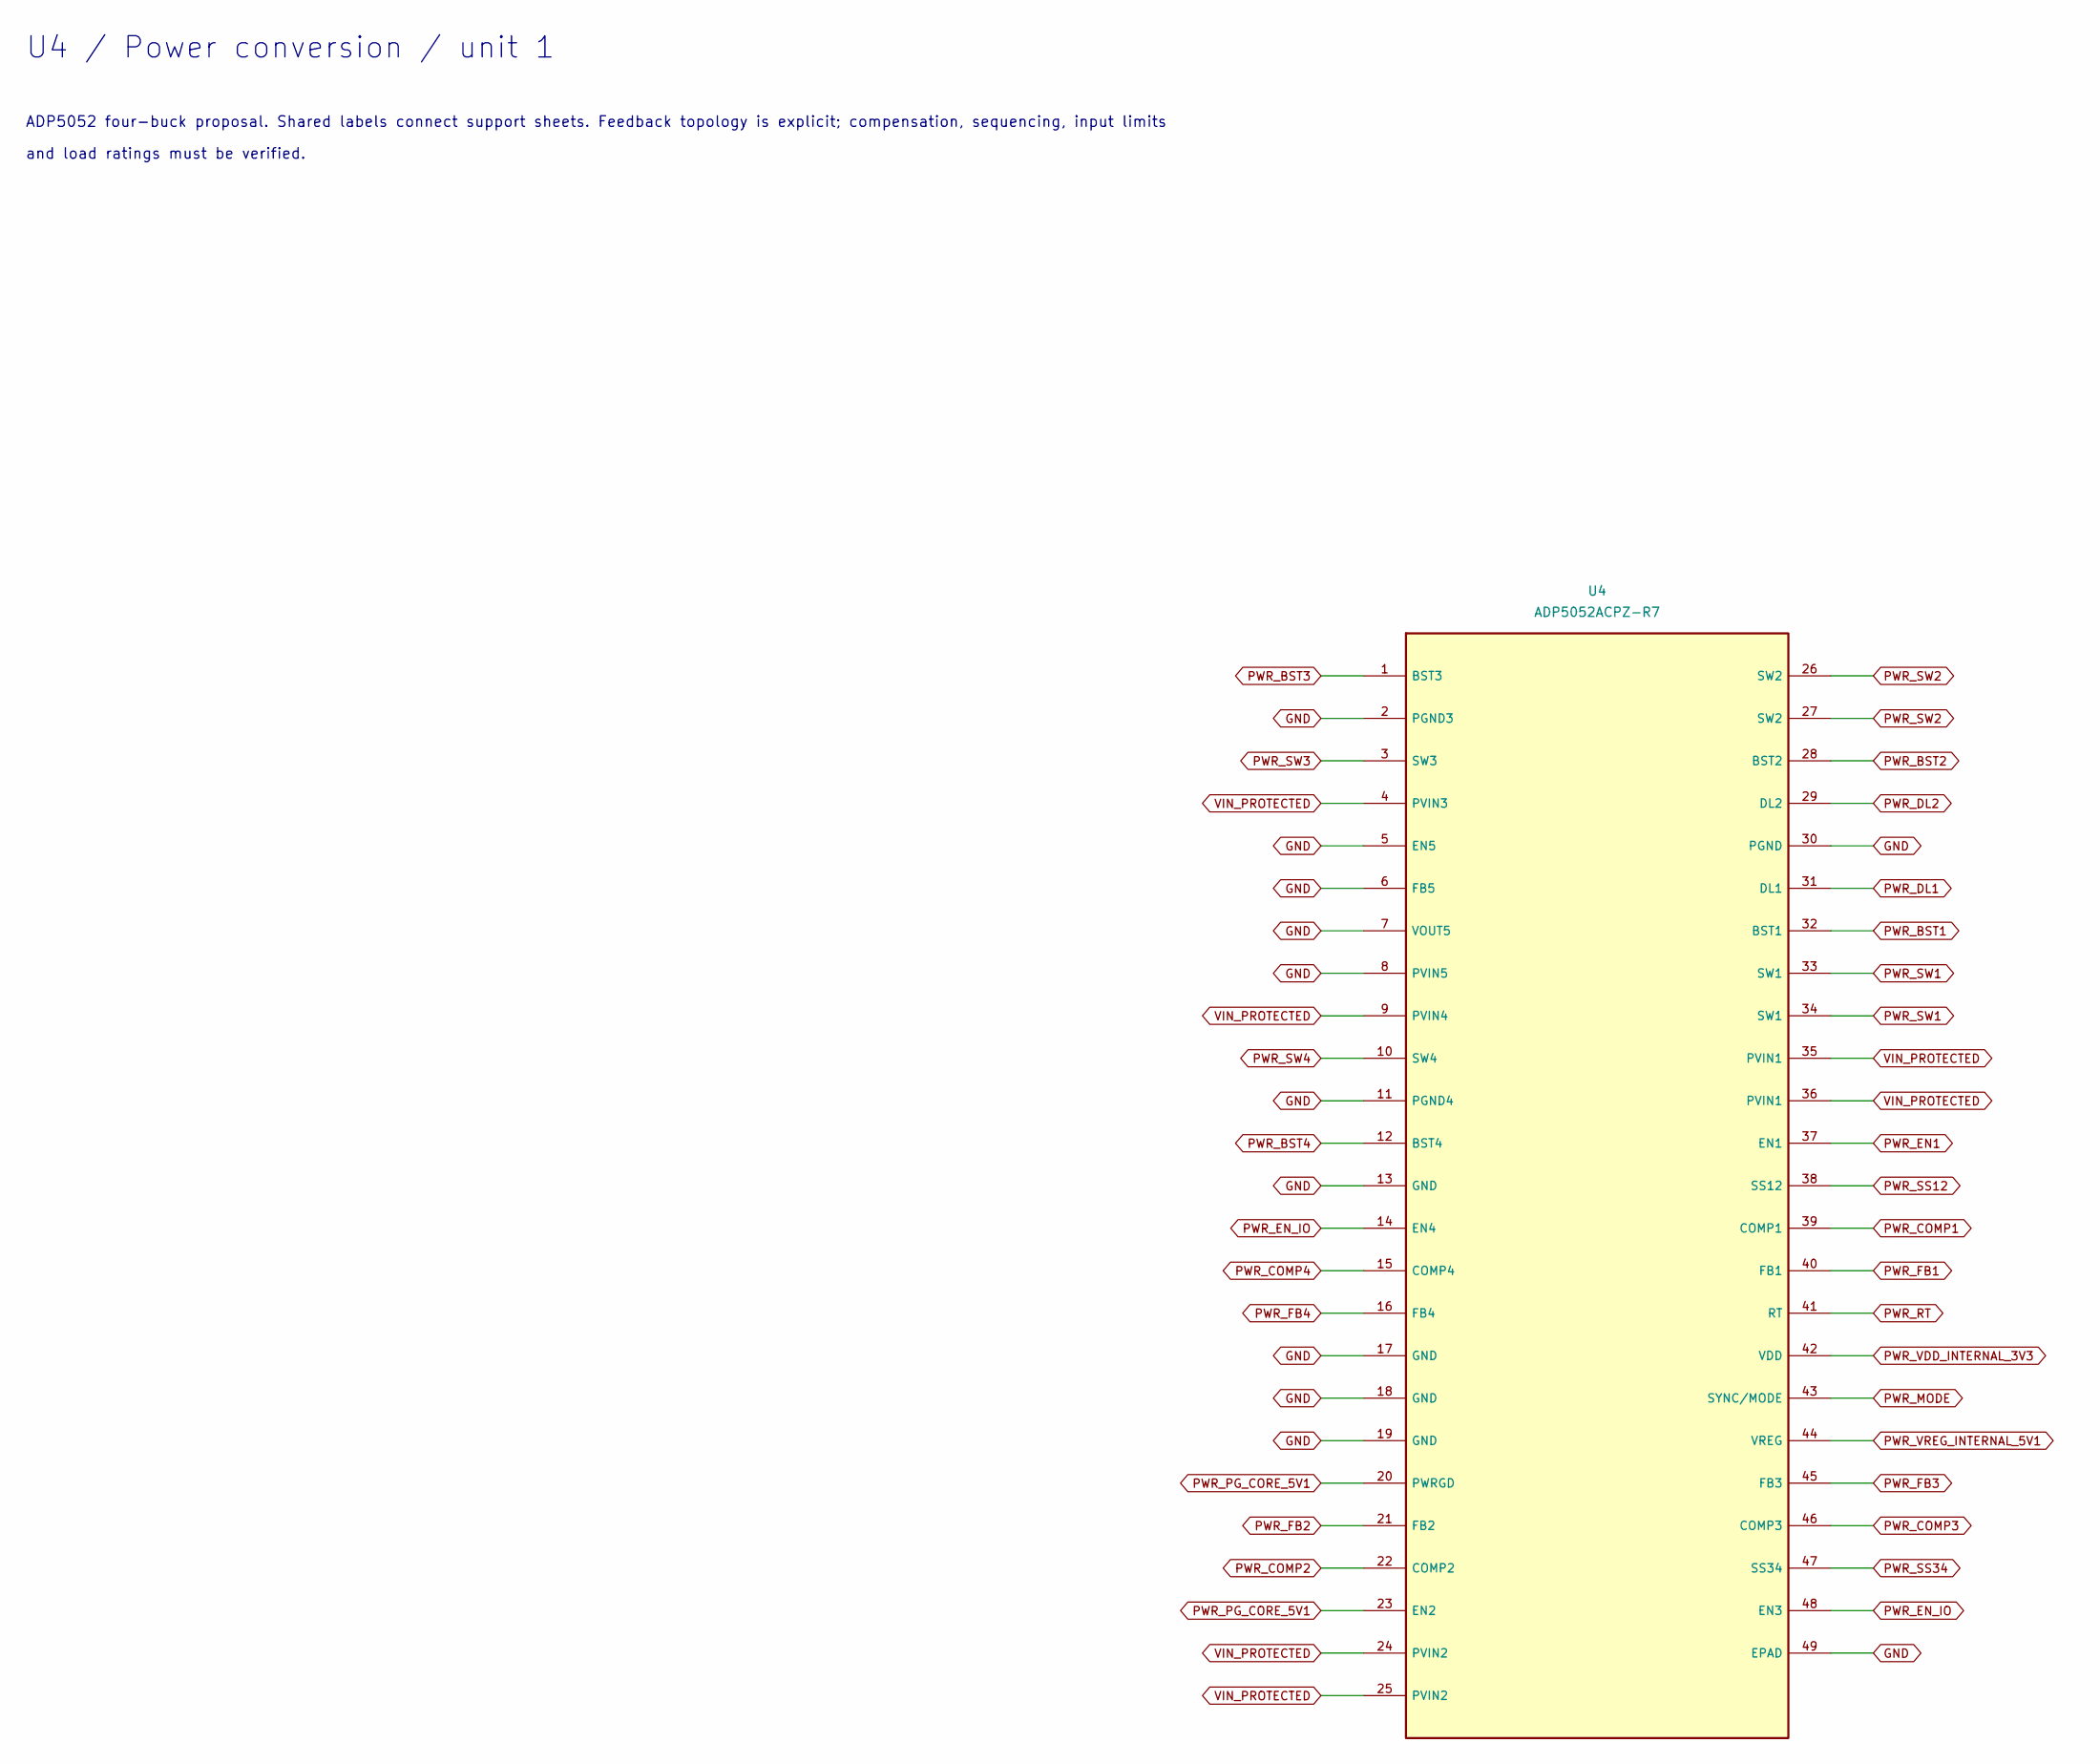
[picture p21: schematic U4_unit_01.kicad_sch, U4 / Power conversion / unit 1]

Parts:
U4: ADP5052ACPZ-R7; ADP5052_CP48_13_DRAFT__U4; Tolerance TBD; Voltage rating TBD; MPN ADP5052ACPZ-R7

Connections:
GND: U4.2 (PGND3), U4.5 (EN5), U4.6 (FB5), U4.7 (VOUT5), U4.8 (PVIN5), U4.11 (PGND4), U4.13 (GND), U4.17 (GND), U4.18 (GND), U4.19 (GND), U4.30 (PGND), U4.49 (EPAD); also elsewhere on the board
PWR_BST1: U4.32 (BST1); also elsewhere on the board
PWR_BST2: U4.28 (BST2); also elsewhere on the board
PWR_BST3: U4.1 (BST3); also elsewhere on the board
PWR_BST4: U4.12 (BST4); also elsewhere on the board
PWR_COMP1: U4.39 (COMP1); also elsewhere on the board
PWR_COMP2: U4.22 (COMP2); also elsewhere on the board
PWR_COMP3: U4.46 (COMP3); also elsewhere on the board
PWR_COMP4: U4.15 (COMP4); also elsewhere on the board
PWR_DL1: U4.31 (DL1); also elsewhere on the board
PWR_DL2: U4.29 (DL2); also elsewhere on the board
PWR_EN1: U4.37 (EN1); also elsewhere on the board
PWR_EN_IO: U4.14 (EN4), U4.48 (EN3); also elsewhere on the board
PWR_FB1: U4.40 (FB1); also elsewhere on the board
PWR_FB2: U4.21 (FB2); also elsewhere on the board
PWR_FB3: U4.45 (FB3); also elsewhere on the board
PWR_FB4: U4.16 (FB4); also elsewhere on the board
PWR_MODE: U4.43 (SYNC/MODE); also elsewhere on the board
PWR_PG_CORE_5V1: U4.20 (PWRGD), U4.23 (EN2); also elsewhere on the board
PWR_RT: U4.41 (RT); also elsewhere on the board
PWR_SS12: U4.38 (SS12); also elsewhere on the board
PWR_SS34: U4.47 (SS34); also elsewhere on the board
PWR_SW1: U4.33 (SW1), U4.34 (SW1); also elsewhere on the board
PWR_SW2: U4.26 (SW2), U4.27 (SW2); also elsewhere on the board
PWR_SW3: U4.3 (SW3); also elsewhere on the board
PWR_SW4: U4.10 (SW4); also elsewhere on the board
PWR_VDD_INTERNAL_3V3: U4.42 (VDD); also elsewhere on the board
PWR_VREG_INTERNAL_5V1: U4.44 (VREG); also elsewhere on the board
VIN_PROTECTED: U4.4 (PVIN3), U4.9 (PVIN4), U4.24 (PVIN2), U4.25 (PVIN2), U4.35 (PVIN1), U4.36 (PVIN1); also elsewhere on the board

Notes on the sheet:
and load ratings must be verified.
ADP5052 four-buck proposal. Shared labels connect support sheets. Feedback topology is explicit; compensation, sequencing, input limits
U4 / Power conversion / unit 1

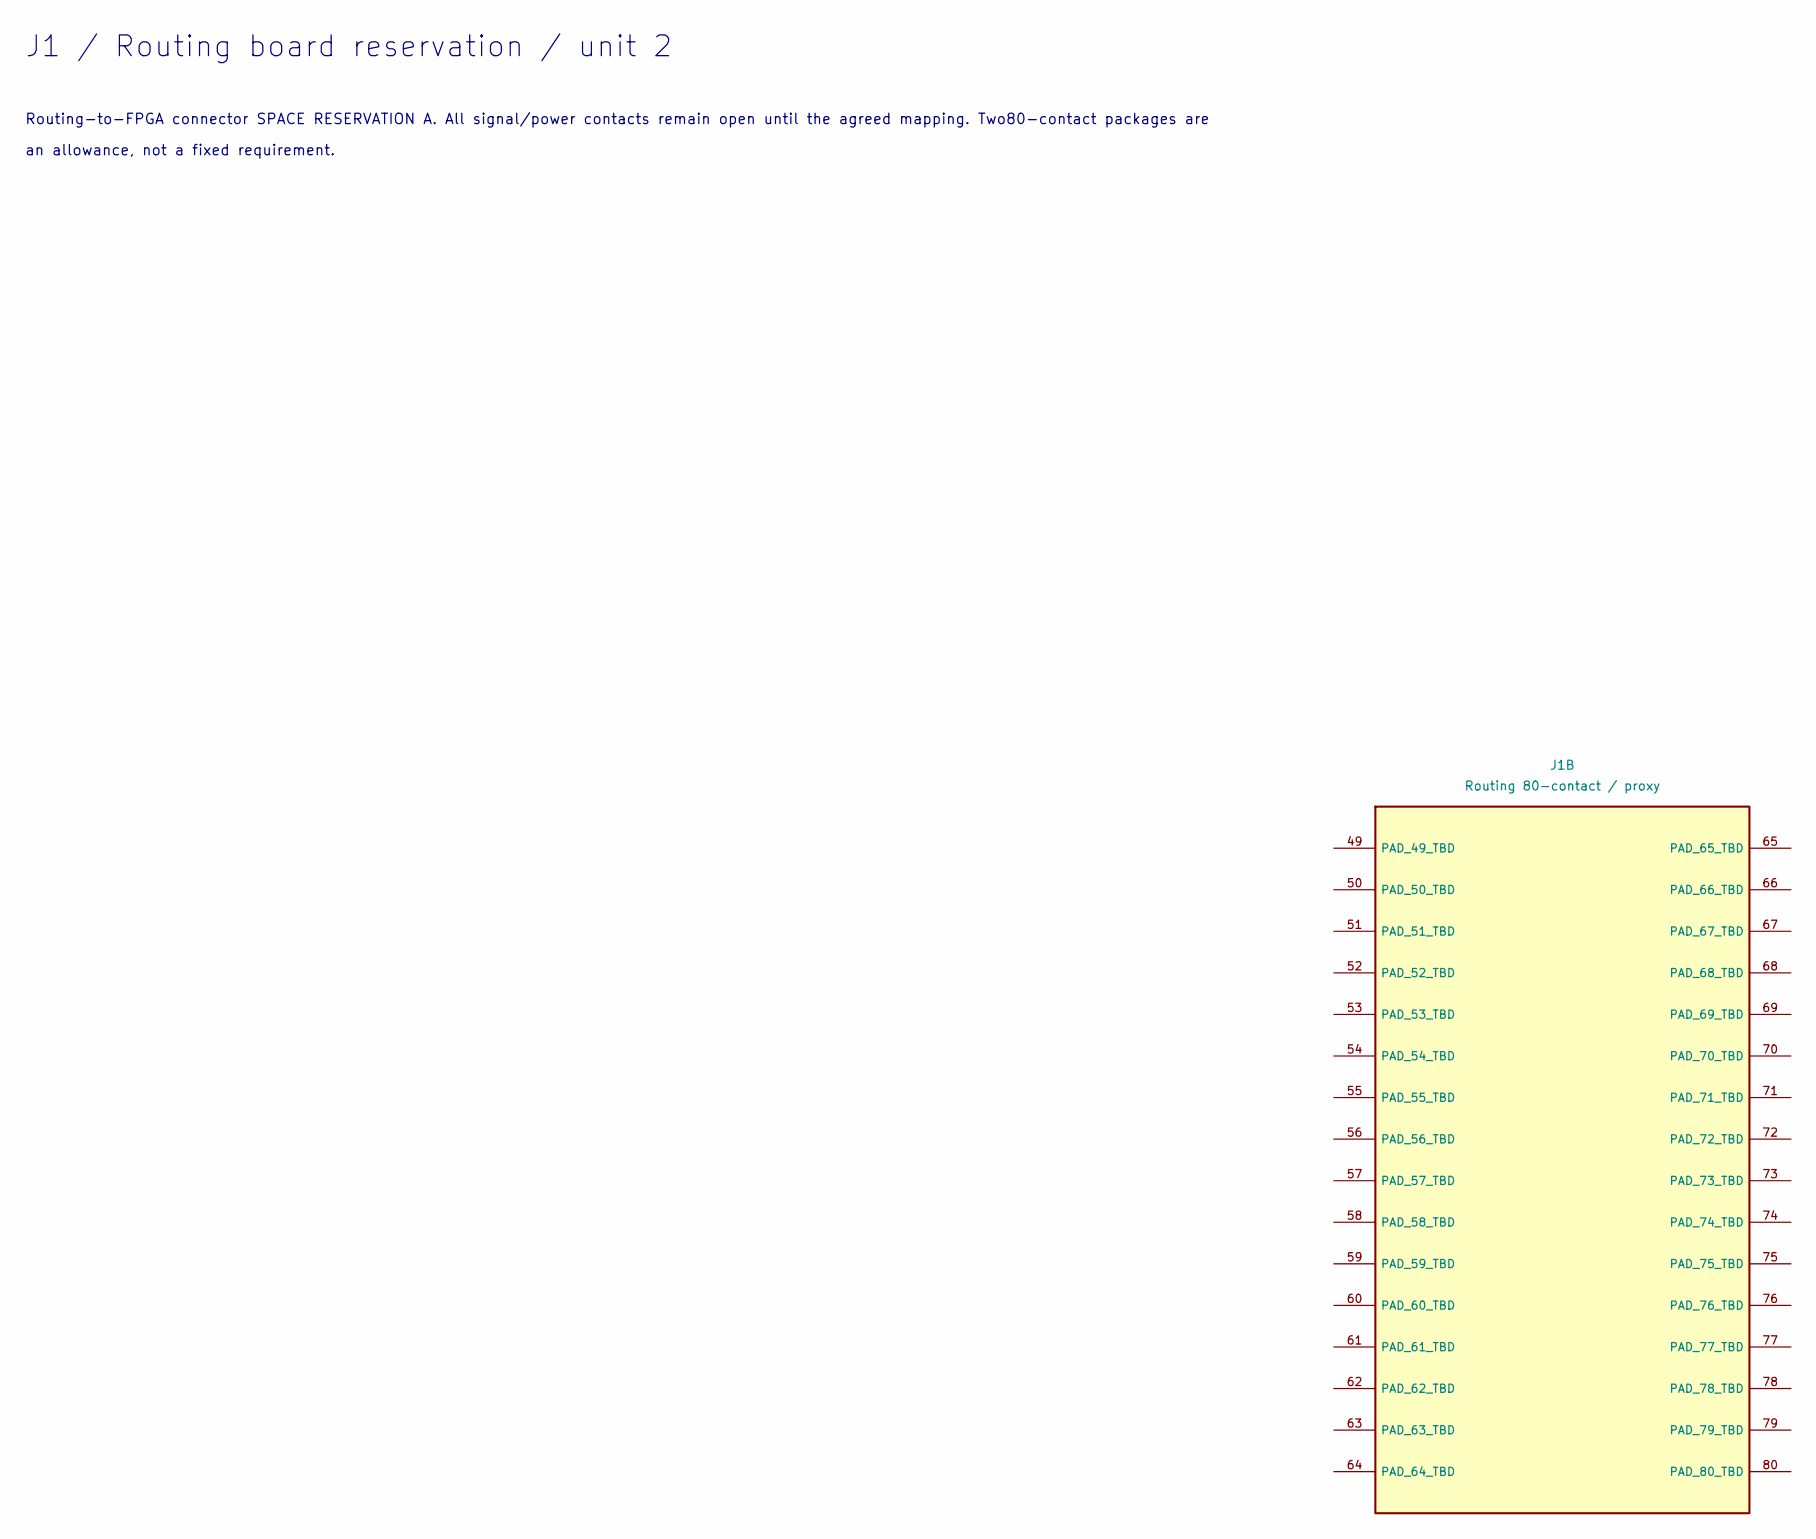
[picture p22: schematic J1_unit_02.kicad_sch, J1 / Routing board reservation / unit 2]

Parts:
J1: Routing 80-contact / proxy; Hirose_DF40C-80DS-0.4V_2x40_P0.4mm__J1; Tolerance TBD; Voltage rating TBD; MPN TBD

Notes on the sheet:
Routing-to-FPGA connector SPACE RESERVATION A. All signal/power contacts remain open until the agreed mapping. Two80-contact packages are
J1 / Routing board reservation / unit 2
an allowance, not a fixed requirement.

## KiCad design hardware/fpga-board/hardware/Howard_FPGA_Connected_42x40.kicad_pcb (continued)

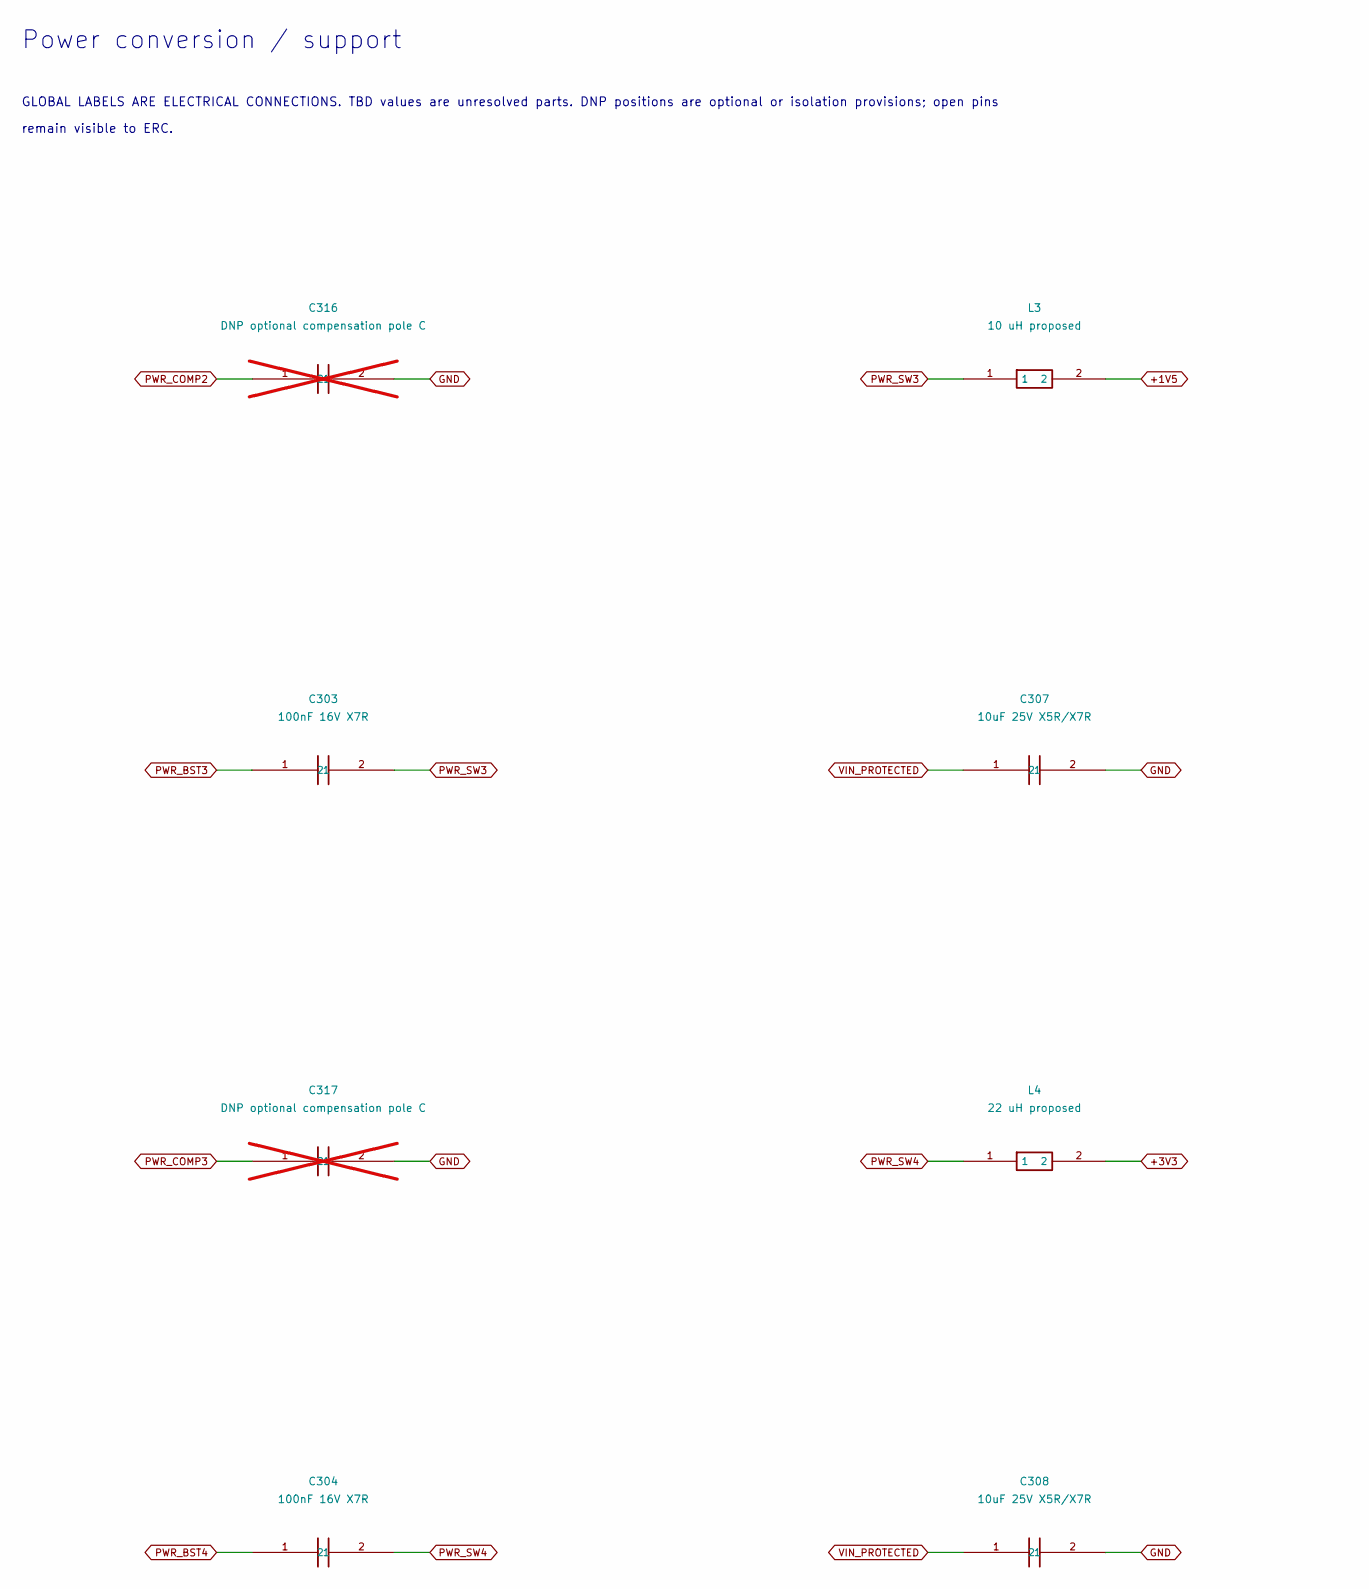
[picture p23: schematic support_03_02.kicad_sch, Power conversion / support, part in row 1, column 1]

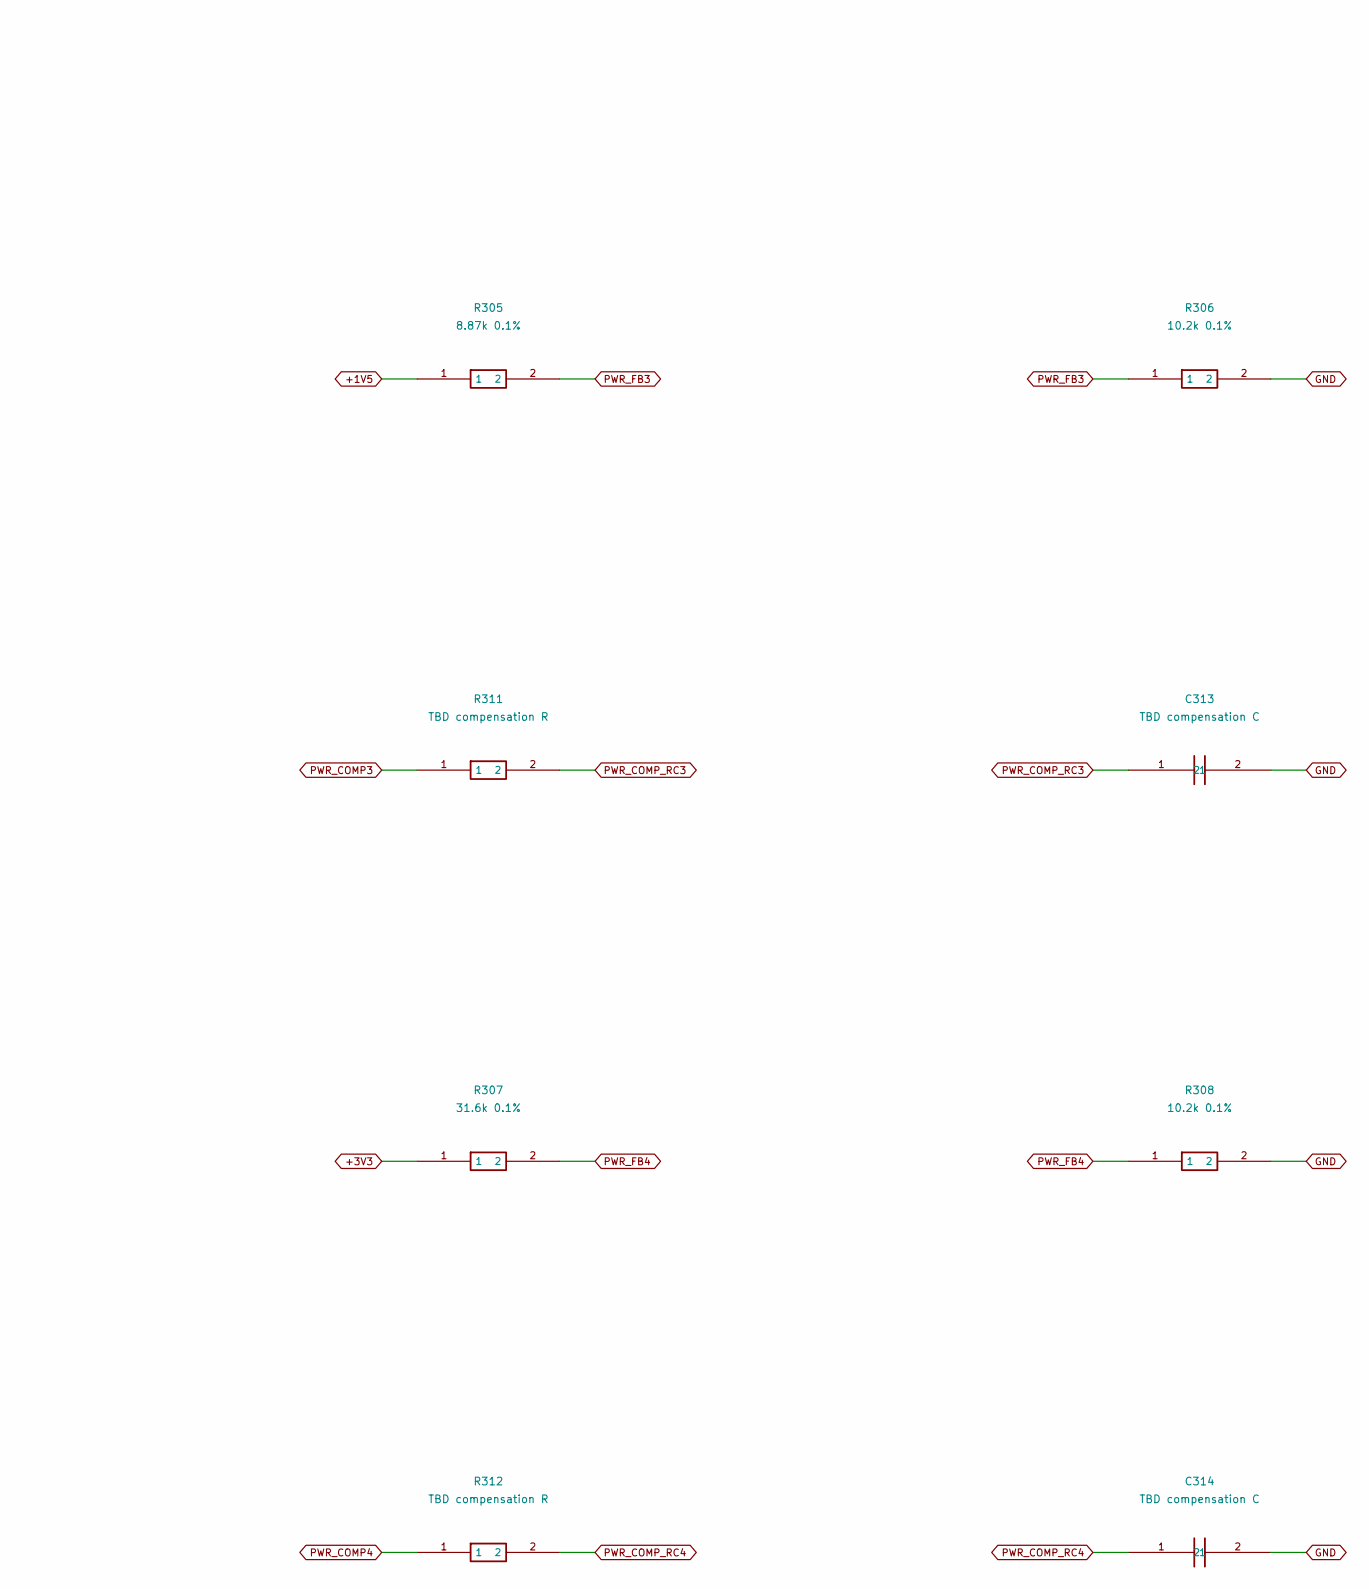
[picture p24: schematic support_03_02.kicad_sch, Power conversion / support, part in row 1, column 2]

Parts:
C303: 100nF 16V X7R; C_0402_1005Metric__C303; Tolerance TBD; Voltage rating TBD; MPN TBD
C304: 100nF 16V X7R; C_0402_1005Metric__C304; Tolerance TBD; Voltage rating TBD; MPN TBD
C307: 10uF 25V X5R/X7R; C_1206_3216Metric__C307; Tolerance TBD; Voltage rating TBD; MPN TBD
C308: 10uF 25V X5R/X7R; C_1206_3216Metric__C308; Tolerance TBD; Voltage rating TBD; MPN TBD
C313: TBD compensation C; C_0402_1005Metric__C313; Tolerance TBD; Voltage rating TBD; MPN TBD
C314: TBD compensation C; C_0402_1005Metric__C314; Tolerance TBD; Voltage rating TBD; MPN TBD
C316: DNP optional compensation pole C; C_0402_1005Metric__C316; Tolerance TBD; Voltage rating TBD; MPN TBD; not fitted
C317: DNP optional compensation pole C; C_0402_1005Metric__C317; Tolerance TBD; Voltage rating TBD; MPN TBD; not fitted
L3: 10 uH proposed; L_Coilcraft_XAL4040-XXX__L3; Tolerance TBD; Voltage rating TBD; MPN XAL4040-103MEC
L4: 22 uH proposed; L_Coilcraft_XAL6060-XXX__L4; Tolerance TBD; Voltage rating TBD; MPN XAL6060-223MEC
R305: 8.87k 0.1%; R_0402_1005Metric__R305; Tolerance TBD; Voltage rating TBD; MPN TBD
R306: 10.2k 0.1%; R_0402_1005Metric__R306; Tolerance TBD; Voltage rating TBD; MPN TBD
R307: 31.6k 0.1%; R_0402_1005Metric__R307; Tolerance TBD; Voltage rating TBD; MPN TBD
R308: 10.2k 0.1%; R_0402_1005Metric__R308; Tolerance TBD; Voltage rating TBD; MPN TBD
R311: TBD compensation R; R_0402_1005Metric__R311; Tolerance TBD; Voltage rating TBD; MPN TBD
R312: TBD compensation R; R_0402_1005Metric__R312; Tolerance TBD; Voltage rating TBD; MPN TBD

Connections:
+1V5: L3.2, R305.1; also elsewhere on the board
+3V3: L4.2, R307.1; also elsewhere on the board
GND: C307.2, C308.2, C313.2, C314.2, C316.2, C317.2, R306.2, R308.2; also elsewhere on the board
PWR_BST3: C303.1; also elsewhere on the board
PWR_BST4: C304.1; also elsewhere on the board
PWR_COMP2: C316.1; also elsewhere on the board
PWR_COMP3: C317.1, R311.1; also elsewhere on the board
PWR_COMP4: R312.1; also elsewhere on the board
PWR_COMP_RC3: C313.1, R311.2
PWR_COMP_RC4: C314.1, R312.2
PWR_FB3: R305.2, R306.1; also elsewhere on the board
PWR_FB4: R307.2, R308.1; also elsewhere on the board
PWR_SW3: C303.2, L3.1; also elsewhere on the board
PWR_SW4: C304.2, L4.1; also elsewhere on the board
VIN_PROTECTED: C307.1, C308.1; also elsewhere on the board

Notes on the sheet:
GLOBAL LABELS ARE ELECTRICAL CONNECTIONS. TBD values are unresolved parts. DNP positions are optional or isolation provisions; open pins
Power conversion / support
remain visible to ERC.

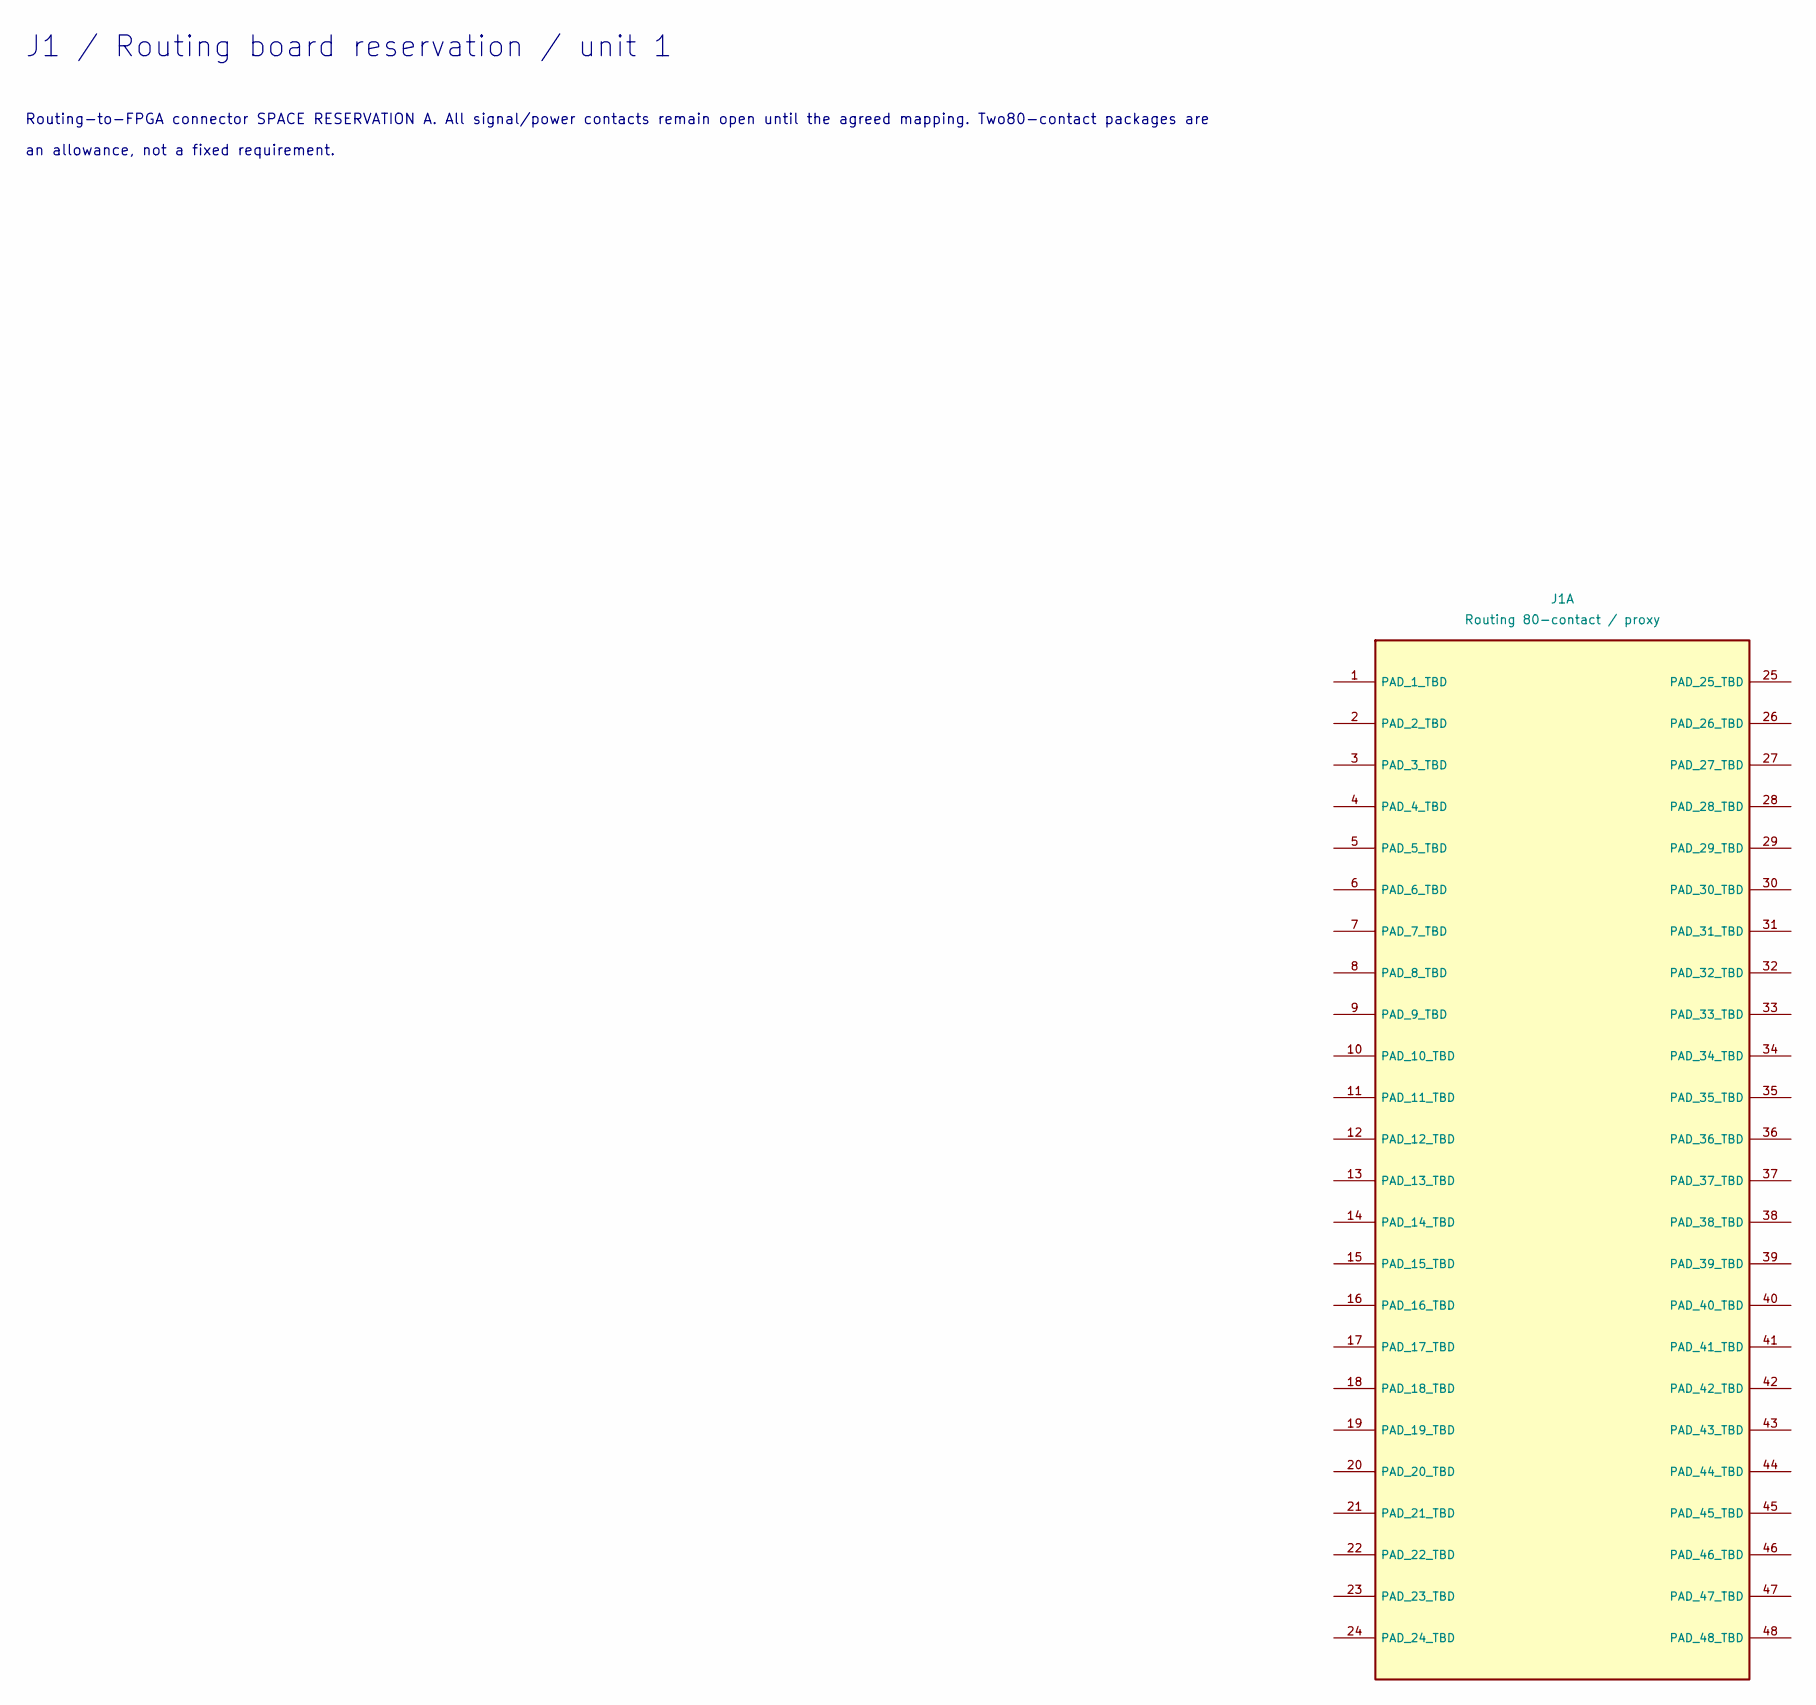
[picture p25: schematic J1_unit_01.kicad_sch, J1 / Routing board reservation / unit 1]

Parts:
J1: Routing 80-contact / proxy; Hirose_DF40C-80DS-0.4V_2x40_P0.4mm__J1; Tolerance TBD; Voltage rating TBD; MPN TBD

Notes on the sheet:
Routing-to-FPGA connector SPACE RESERVATION A. All signal/power contacts remain open until the agreed mapping. Two80-contact packages are
J1 / Routing board reservation / unit 1
an allowance, not a fixed requirement.

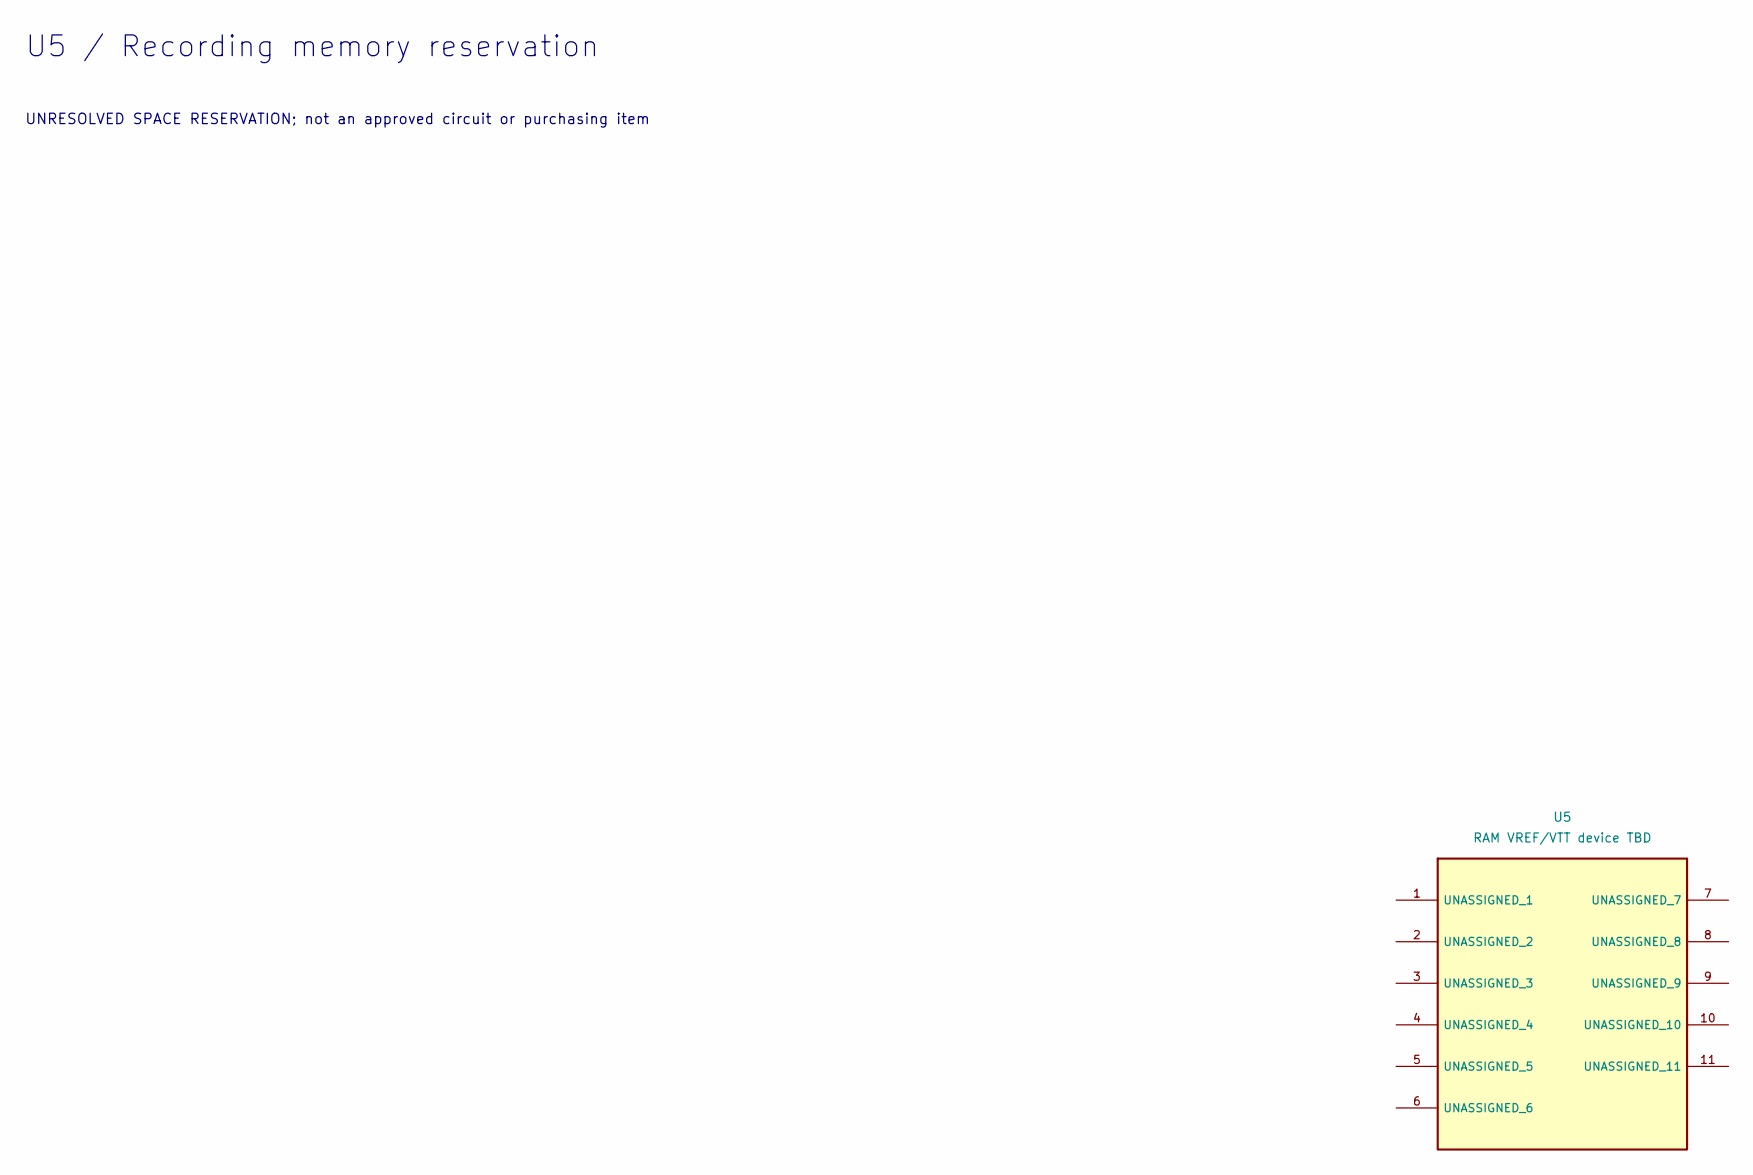
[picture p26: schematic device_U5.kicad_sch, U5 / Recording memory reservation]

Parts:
U5: RAM VREF/VTT device TBD; VSON-10-1EP_3x3mm_P0.5mm_EP1.2x2mm__U5; Tolerance TBD; Voltage rating TBD; MPN TBD

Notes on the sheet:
U5 / Recording memory reservation
UNRESOLVED SPACE RESERVATION; not an approved circuit or purchasing item

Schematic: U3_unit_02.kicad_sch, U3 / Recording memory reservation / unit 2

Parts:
U3: Recording RAM / exact part TBD; Micron_FBGA-96_8x14mm_Layout9x16_P0.8mm__U3; Tolerance TBD; Voltage rating TBD; MPN TBD

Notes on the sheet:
are not an approved DDR netlist.
U3 / Recording memory reservation / unit 2
ONE recording-RAM package reservation. Exact device, capacity, signal map, controller and supply/termination requirements TBD. Pad numbers

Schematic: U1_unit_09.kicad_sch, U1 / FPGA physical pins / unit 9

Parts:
U1: XC7A200T-1SBG484C; Xilinx_SBG484__U1; Tolerance TBD; Voltage rating TBD; MPN XC7A200T-1SBG484C

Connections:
+1V0: U1.H8 (VCCINT), U1.H10 (VCCINT), U1.J7 (VCCINT), U1.J9 (VCCINT), U1.K8 (VCCINT), U1.L7 (VCCINT), U1.M8 (VCCINT), U1.N7 (VCCINT), U1.P8 (VCCINT), U1.P10 (VCCINT), U1.R7 (VCCINT), U1.R9 (VCCINT), U1.T8 (VCCINT), U1.T10 (VCCINT); also elsewhere on the board
+1V8: U1.H12 (VCCAUX), U1.K12 (VCCAUX), U1.M12 (VCCAUX), U1.P12 (VCCAUX), U1.R11 (VCCAUX); also elsewhere on the board
+3V3: U1.F12 (VCCO_0), U1.T12 (VCCO_0); also elsewhere on the board
GND: U1.A2 (GND), U1.A3 (GND), U1.A5 (GND), U1.A7 (GND), U1.A9 (GND), U1.A11 (GND), U1.A12 (GND), U1.A22 (GND), U1.AA2 (GND), U1.AA12 (GND), U1.AA22 (GND), U1.AB9 (GND), U1.AB19 (GND), U1.B3 (GND), U1.B12 (GND), U1.B19 (GND), U1.C3 (GND), U1.C6 (GND), U1.C10 (GND), U1.C12 (GND), U1.C16 (GND), U1.D3 (GND), U1.D4 (GND), U1.D8 (GND), U1.D12 (GND), U1.D13 (GND), U1.E4 (GND), U1.E5 (GND), U1.E7 (GND), U1.E9 (GND), U1.E11 (GND), U1.E20 (GND), U1.F11 (GND), U1.F17 (GND); also elsewhere on the board
VCCO_13_TBD: U1.Y10 (VCCO_13); also elsewhere on the board

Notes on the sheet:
U1 / FPGA physical pins / unit 9
bank plan or timing constraints.
Exact XC7A200T SBG484 physical pin map. Boot and core rails are drafted. Unassigned acquisition/link/DDR pins remain open; no completed

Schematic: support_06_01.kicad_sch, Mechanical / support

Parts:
H1: M2 mounting; MountingHole_2.2mm_M2__H1; Tolerance TBD; Voltage rating TBD; MPN Non-plated PCB mounting hole
H2: M2 mounting; MountingHole_2.2mm_M2__H2; Tolerance TBD; Voltage rating TBD; MPN Non-plated PCB mounting hole
H3: M2 mounting; MountingHole_2.2mm_M2__H3; Tolerance TBD; Voltage rating TBD; MPN Non-plated PCB mounting hole
H4: M2 mounting; MountingHole_2.2mm_M2__H4; Tolerance TBD; Voltage rating TBD; MPN Non-plated PCB mounting hole

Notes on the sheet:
GLOBAL LABELS ARE ELECTRICAL CONNECTIONS. TBD values are unresolved parts. DNP positions are optional or isolation provisions; open pins
Mechanical / support
remain visible to ERC.

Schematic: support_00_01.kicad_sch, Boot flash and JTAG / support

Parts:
J4: JTAG_CUSTOM_2x3_1.27mm; PinHeader_2x03_P1.27mm_Vertical__J4; Tolerance TBD; Voltage rating TBD; MPN TBD
R101: 4.7kOhm; R_0201_0603Metric__R101; Tolerance 1%; Voltage rating 30 V limiting voltage; MPN CRCW02014K70FKED
R102: 4.7kOhm; R_0201_0603Metric__R102; Tolerance 1%; Voltage rating 30 V limiting voltage; MPN CRCW02014K70FKED
R103: 10kOhm; R_0201_0603Metric__R103; Tolerance 1%; Voltage rating 30 V limiting voltage; MPN CRCW020110K0FKED
R104: 4.7kOhm; R_0201_0603Metric__R104; Tolerance 1%; Voltage rating 30 V limiting voltage; MPN CRCW02014K70FKED
R105: 4.7kOhm; R_0201_0603Metric__R105; Tolerance 1%; Voltage rating 30 V limiting voltage; MPN CRCW02014K70FKED
R106: 4.7kOhm; R_0201_0603Metric__R106; Tolerance 1%; Voltage rating 30 V limiting voltage; MPN CRCW02014K70FKED
R107: 1kOhm; R_0201_0603Metric__R107; Tolerance 1%; Voltage rating 30 V limiting voltage; MPN CRCW02011K00FKED
R108: 1kOhm; R_0201_0603Metric__R108; Tolerance 1%; Voltage rating 30 V limiting voltage; MPN CRCW02011K00FKED
R109: 1kOhm; R_0201_0603Metric__R109; Tolerance 1%; Voltage rating 30 V limiting voltage; MPN CRCW02011K00FKED
R110: 1kOhm; R_0201_0603Metric__R110; Tolerance 1%; Voltage rating 30 V limiting voltage; MPN CRCW02011K00FKED
R111: 22Ohm; R_0201_0603Metric__R111; Tolerance 1%; Voltage rating 30 V limiting voltage; MPN CRCW020122R0FNED
R112: 0Ohm; R_0201_0603Metric__R112; Tolerance jumper <=50mOhm; Voltage rating 30 V limiting voltage; MPN CRCW02010000Z0ED
R113: 0Ohm; R_0201_0603Metric__R113; Tolerance jumper <=50mOhm; Voltage rating 30 V limiting voltage; MPN CRCW02010000Z0ED
R114: 0Ohm; R_0201_0603Metric__R114; Tolerance jumper <=50mOhm; Voltage rating 30 V limiting voltage; MPN CRCW02010000Z0ED
SW1: PROGRAM_B_RESET; SW_SPST_TL3305A__SW1; Tolerance TBD; Voltage rating TBD; MPN TBD

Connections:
+3V3: J4.1 (VTREF), R101.2, R102.2, R103.2, R104.2, R105.2, R106.2, R107.2, R110.2; also elsewhere on the board
CCLK_FPGA: R111.1; also elsewhere on the board
DONE: R103.1; also elsewhere on the board
GND: J4.2 (GND), R108.2, R109.2, SW1.2 (B); also elsewhere on the board
INIT_B: R102.1; also elsewhere on the board
JTAG_TCK: J4.3 (TCK); also elsewhere on the board
JTAG_TDI: J4.5 (TDI); also elsewhere on the board
JTAG_TDO: J4.6 (TDO); also elsewhere on the board
JTAG_TMS: J4.4 (TMS); also elsewhere on the board
MODE_M0: R107.1; also elsewhere on the board
MODE_M1: R108.1; also elsewhere on the board
MODE_M2: R109.1; also elsewhere on the board
PROGRAM_B: R101.1, SW1.1 (A); also elsewhere on the board
PUDC_B: R110.1; also elsewhere on the board
QSPI_CS_N: R104.1; also elsewhere on the board
QSPI_IO0: R112.2; also elsewhere on the board
QSPI_IO0_FPGA: R112.1; also elsewhere on the board
QSPI_IO1: R113.2; also elsewhere on the board
QSPI_IO1_FPGA: R113.1; also elsewhere on the board
QSPI_IO2: R105.1, R114.2; also elsewhere on the board
QSPI_IO2_FPGA: R114.1; also elsewhere on the board
QSPI_IO3: R106.1; also elsewhere on the board
QSPI_SCK: R111.2; also elsewhere on the board

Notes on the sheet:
GLOBAL LABELS ARE ELECTRICAL CONNECTIONS. TBD values are unresolved parts. DNP positions are optional or isolation provisions; open pins
Boot flash and JTAG / support
remain visible to ERC.

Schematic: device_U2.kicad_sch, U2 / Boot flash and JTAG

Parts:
U2: S25FL256SAGMFI000; SOIC-16W_7.5x10.3mm_P1.27mm__U2; Tolerance TBD; Voltage rating TBD; MPN S25FL256SAGMFI000

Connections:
+3V3: U2.2 (VCC); also elsewhere on the board
GND: U2.10 (VSS); also elsewhere on the board
QSPI_CS_N: U2.7 (CS#); also elsewhere on the board
QSPI_IO0: U2.15 (SI/IO0); also elsewhere on the board
QSPI_IO1: U2.8 (SO/IO1); also elsewhere on the board
QSPI_IO2: U2.9 (WP#/IO2); also elsewhere on the board
QSPI_IO3: U2.1 (HOLD#/IO3); also elsewhere on the board
QSPI_SCK: U2.16 (SCK); also elsewhere on the board

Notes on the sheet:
U2 / Boot flash and JTAG
PROPOSED

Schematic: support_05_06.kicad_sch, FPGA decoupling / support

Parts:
C81: 0.47uF; C_0201_0603Metric__C81; Tolerance 20%; Voltage rating 10 V; MPN C0603X5R1A474M030BC
C82: 0.47uF; C_0201_0603Metric__C82; Tolerance 20%; Voltage rating 10 V; MPN C0603X5R1A474M030BC
C83: 47uF; C_1210_3225Metric__C83; Tolerance TBD; Voltage rating TBD; MPN TBD
C84: 100nF; C_0402_1005Metric__C84; Tolerance 10%; Voltage rating 16 V; MPN C1005X7R1C104K050BC

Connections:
+1V8: C84.1; also elsewhere on the board
GND: C81.2, C82.2, C83.2, C84.2; also elsewhere on the board
VCCO_35_TBD: C81.1, C82.1, C83.1; also elsewhere on the board

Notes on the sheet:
GLOBAL LABELS ARE ELECTRICAL CONNECTIONS. TBD values are unresolved parts. DNP positions are optional or isolation provisions; open pins
FPGA decoupling / support
remain visible to ERC.

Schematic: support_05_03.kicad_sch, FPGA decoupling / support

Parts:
C33: 4.7uF; C_0402_1005Metric__C33; Tolerance 10%; Voltage rating 10 V; MPN C1005X5R1A475K050BC
C34: 4.7uF; C_0402_1005Metric__C34; Tolerance 10%; Voltage rating 10 V; MPN C1005X5R1A475K050BC
C35: 4.7uF; C_0402_1005Metric__C35; Tolerance 10%; Voltage rating 10 V; MPN C1005X5R1A475K050BC
C36: 0.47uF; C_0201_0603Metric__C36; Tolerance 20%; Voltage rating 10 V; MPN C0603X5R1A474M030BC
C37: 0.47uF; C_0201_0603Metric__C37; Tolerance 20%; Voltage rating 10 V; MPN C0603X5R1A474M030BC
C38: 0.47uF; C_0201_0603Metric__C38; Tolerance 20%; Voltage rating 10 V; MPN C0603X5R1A474M030BC
C39: 0.47uF; C_0201_0603Metric__C39; Tolerance 20%; Voltage rating 10 V; MPN C0603X5R1A474M030BC
C40: 0.47uF; C_0201_0603Metric__C40; Tolerance 20%; Voltage rating 10 V; MPN C0603X5R1A474M030BC
C41: 47uF; C_1210_3225Metric__C41; Tolerance TBD; Voltage rating TBD; MPN TBD
C42: 4.7uF; C_0402_1005Metric__C42; Tolerance 10%; Voltage rating 10 V; MPN C1005X5R1A475K050BC
C43: 4.7uF; C_0402_1005Metric__C43; Tolerance 10%; Voltage rating 10 V; MPN C1005X5R1A475K050BC
C44: 0.47uF; C_0201_0603Metric__C44; Tolerance 20%; Voltage rating 10 V; MPN C0603X5R1A474M030BC
C45: 0.47uF; C_0201_0603Metric__C45; Tolerance 20%; Voltage rating 10 V; MPN C0603X5R1A474M030BC
C46: 0.47uF; C_0201_0603Metric__C46; Tolerance 20%; Voltage rating 10 V; MPN C0603X5R1A474M030BC
C47: 0.47uF; C_0201_0603Metric__C47; Tolerance 20%; Voltage rating 10 V; MPN C0603X5R1A474M030BC
C48: 47uF; C_1210_3225Metric__C48; Tolerance TBD; Voltage rating TBD; MPN TBD

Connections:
+1V8: C33.1, C34.1, C35.1, C36.1, C37.1, C38.1, C39.1, C40.1; also elsewhere on the board
+3V3: C41.1; also elsewhere on the board
GND: C33.2, C34.2, C35.2, C36.2, C37.2, C38.2, C39.2, C40.2, C41.2, C42.2, C43.2, C44.2, C45.2, C46.2, C47.2, C48.2; also elsewhere on the board
VCCO_13_TBD: C42.1, C43.1, C44.1, C45.1, C46.1, C47.1, C48.1; also elsewhere on the board

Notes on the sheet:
GLOBAL LABELS ARE ELECTRICAL CONNECTIONS. TBD values are unresolved parts. DNP positions are optional or isolation provisions; open pins
FPGA decoupling / support
remain visible to ERC.

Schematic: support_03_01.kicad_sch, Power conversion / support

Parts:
C301: 100nF 16V X7R; C_0402_1005Metric__C301; Tolerance TBD; Voltage rating TBD; MPN TBD
C302: 100nF 16V X7R; C_0402_1005Metric__C302; Tolerance TBD; Voltage rating TBD; MPN TBD
C305: 10uF 25V X5R/X7R; C_1206_3216Metric__C305; Tolerance TBD; Voltage rating TBD; MPN TBD
C306: 10uF 25V X5R/X7R; C_1206_3216Metric__C306; Tolerance TBD; Voltage rating TBD; MPN TBD
C311: TBD compensation C; C_0402_1005Metric__C311; Tolerance TBD; Voltage rating TBD; MPN TBD
C312: TBD compensation C; C_0402_1005Metric__C312; Tolerance TBD; Voltage rating TBD; MPN TBD
C315: DNP optional compensation pole C; C_0402_1005Metric__C315; Tolerance TBD; Voltage rating TBD; MPN TBD; not fitted
L1: 3.3 uH proposed; L_Coilcraft_XAL6030-XXX__L1; Tolerance TBD; Voltage rating TBD; MPN XAL6030-332MEC
L2: 4.7 uH proposed; L_Coilcraft_XAL6060-XXX__L2; Tolerance TBD; Voltage rating TBD; MPN XAL6060-472MEC
Q1: Si7232DN-T1-GE3 - ONE dual NFET package; Vishay_PowerPAK_1212-8_Dual__Q1; Tolerance TBD; Voltage rating TBD; MPN Si7232DN-T1-GE3
R301: 2.49k 0.1%; R_0402_1005Metric__R301; Tolerance TBD; Voltage rating TBD; MPN TBD
R302: 10k 0.1%; R_0402_1005Metric__R302; Tolerance TBD; Voltage rating TBD; MPN TBD
R303: 12.7k 0.1%; R_0402_1005Metric__R303; Tolerance TBD; Voltage rating TBD; MPN TBD
R304: 10.2k 0.1%; R_0402_1005Metric__R304; Tolerance TBD; Voltage rating TBD; MPN TBD
R309: TBD compensation R; R_0402_1005Metric__R309; Tolerance TBD; Voltage rating TBD; MPN TBD
R310: TBD compensation R; R_0402_1005Metric__R310; Tolerance TBD; Voltage rating TBD; MPN TBD

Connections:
+1V0: L1.2, R301.1; also elsewhere on the board
+1V8: L2.2, R303.1; also elsewhere on the board
GND: C305.2, C306.2, C311.2, C312.2, C315.2, Q1.1 (S1), Q1.3 (S2), R302.2, R304.2; also elsewhere on the board
PWR_BST1: C301.1; also elsewhere on the board
PWR_BST2: C302.1; also elsewhere on the board
PWR_COMP1: C315.1, R309.1; also elsewhere on the board
PWR_COMP2: R310.1; also elsewhere on the board
PWR_COMP_RC1: C311.1, R309.2
PWR_COMP_RC2: C312.1, R310.2
PWR_DL1: Q1.2 (G1); also elsewhere on the board
PWR_DL2: Q1.4 (G2); also elsewhere on the board
PWR_FB1: R301.2, R302.1; also elsewhere on the board
PWR_FB2: R303.2, R304.1; also elsewhere on the board
PWR_SW1: C301.2, L1.1, Q1.6 (D1_[physical_7+8]); also elsewhere on the board
PWR_SW2: C302.2, L2.1, Q1.5 (D2_[physical_5+6]); also elsewhere on the board
VIN_PROTECTED: C305.1, C306.1; also elsewhere on the board

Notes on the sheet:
GLOBAL LABELS ARE ELECTRICAL CONNECTIONS. TBD values are unresolved parts. DNP positions are optional or isolation provisions; open pins
Power conversion / support
remain visible to ERC.

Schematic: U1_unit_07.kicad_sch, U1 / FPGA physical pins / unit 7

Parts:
U1: XC7A200T-1SBG484C; Xilinx_SBG484__U1; Tolerance TBD; Voltage rating TBD; MPN XC7A200T-1SBG484C

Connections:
+3V3: U1.U8 (CFGBVS_0); also elsewhere on the board
CCLK_FPGA: U1.L12 (CCLK_0); also elsewhere on the board
DONE: U1.G11 (DONE_0); also elsewhere on the board
INIT_B: U1.U12 (INIT_B_0); also elsewhere on the board
JTAG_TCK: U1.V12 (TCK_0); also elsewhere on the board
JTAG_TDI: U1.R13 (TDI_0); also elsewhere on the board
JTAG_TDO: U1.U13 (TDO_0); also elsewhere on the board
JTAG_TMS: U1.T13 (TMS_0); also elsewhere on the board
MODE_M0: U1.U11 (M0_0); also elsewhere on the board
MODE_M1: U1.U10 (M1_0); also elsewhere on the board
MODE_M2: U1.U9 (M2_0); also elsewhere on the board
PROGRAM_B: U1.N12 (PROGRAM_B_0); also elsewhere on the board

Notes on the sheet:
bank plan or timing constraints.
U1 / FPGA physical pins / unit 7
Exact XC7A200T SBG484 physical pin map. Boot and core rails are drafted. Unassigned acquisition/link/DDR pins remain open; no completed

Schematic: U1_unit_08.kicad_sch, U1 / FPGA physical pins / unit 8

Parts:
U1: XC7A200T-1SBG484C; Xilinx_SBG484__U1; Tolerance TBD; Voltage rating TBD; MPN XC7A200T-1SBG484C

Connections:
+1V8: U1.K10 (VCCADC_0); also elsewhere on the board
GND: U1.F5 (GND), U1.G5 (GND), U1.G6 (GND), U1.G7 (GND), U1.G8 (GND), U1.G9 (GND), U1.G10 (GND), U1.G12 (GND), U1.G14 (GND), U1.H1 (GND), U1.H7 (GND), U1.H9 (GND), U1.H11 (GND), U1.H21 (GND), U1.J8 (GND), U1.J10 (GND), U1.J12 (GND), U1.J18 (GND), U1.K5 (GND), U1.K7 (GND), U1.K9 (GNDADC_0), U1.K11 (GND), U1.K15 (GND), U1.L2 (GND), U1.L8 (GND), U1.L22 (GND), U1.M7 (GND), U1.M11 (GND), U1.M19 (GND), U1.N6 (GND), U1.N8 (GND), U1.N16 (GND), U1.P3 (GND), U1.P7 (GND), U1.P9 (GND), U1.P11 (GND), U1.P13 (GND), U1.R8 (GND), U1.R10 (GND), U1.R12 (GND), U1.R20 (GND), U1.T7 (GND), U1.T9 (GND), U1.T11 (GND), U1.T17 (GND), U1.U4 (GND), U1.U14 (GND), U1.V1 (GND), U1.V11 (GND), U1.V21 (GND), U1.W8 (GND), U1.W18 (GND), U1.Y5 (GND), U1.Y15 (GND); also elsewhere on the board

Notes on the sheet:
U1 / FPGA physical pins / unit 8
bank plan or timing constraints.
Exact XC7A200T SBG484 physical pin map. Boot and core rails are drafted. Unassigned acquisition/link/DDR pins remain open; no completed

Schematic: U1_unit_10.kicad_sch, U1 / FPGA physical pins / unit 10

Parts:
U1: XC7A200T-1SBG484C; Xilinx_SBG484__U1; Tolerance TBD; Voltage rating TBD; MPN XC7A200T-1SBG484C

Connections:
+1V0: U1.J11 (VCCBRAM), U1.L11 (VCCBRAM), U1.N11 (VCCBRAM); also elsewhere on the board
+3V3: U1.M14 (VCCO_14), U1.P18 (VCCO_14), U1.R15 (VCCO_14), U1.T22 (VCCO_14), U1.U19 (VCCO_14), U1.Y20 (VCCO_14); also elsewhere on the board
VCCO_13_TBD: U1.AA17 (VCCO_13), U1.AB14 (VCCO_13), U1.V16 (VCCO_13), U1.W13 (VCCO_13); also elsewhere on the board
VCCO_15_TBD: U1.G19 (VCCO_15), U1.H16 (VCCO_15), U1.J13 (VCCO_15), U1.K20 (VCCO_15), U1.L17 (VCCO_15), U1.N21 (VCCO_15); also elsewhere on the board
VCCO_16_TBD: U1.A17 (VCCO_16), U1.B14 (VCCO_16), U1.C21 (VCCO_16), U1.D18 (VCCO_16), U1.E15 (VCCO_16), U1.F22 (VCCO_16); also elsewhere on the board
VCCO_34_TBD: U1.AA7 (VCCO_34), U1.AB4 (VCCO_34), U1.R5 (VCCO_34), U1.T2 (VCCO_34), U1.V6 (VCCO_34), U1.W3 (VCCO_34); also elsewhere on the board
VCCO_35_TBD: U1.C1 (VCCO_35), U1.F2 (VCCO_35), U1.H6 (VCCO_35), U1.J3 (VCCO_35), U1.M4 (VCCO_35), U1.N1 (VCCO_35); also elsewhere on the board

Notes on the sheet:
bank plan or timing constraints.
Exact XC7A200T SBG484 physical pin map. Boot and core rails are drafted. Unassigned acquisition/link/DDR pins remain open; no completed
U1 / FPGA physical pins / unit 10

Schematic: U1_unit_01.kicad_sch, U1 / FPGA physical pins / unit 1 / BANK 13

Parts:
U1: XC7A200T-1SBG484C; Xilinx_SBG484__U1; Tolerance TBD; Voltage rating TBD; MPN XC7A200T-1SBG484C

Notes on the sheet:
U1 / FPGA physical pins / unit 1 / BANK 13
bank plan or timing constraints.
Exact XC7A200T SBG484 physical pin map. Boot and core rails are drafted. Unassigned acquisition/link/DDR pins remain open; no completed

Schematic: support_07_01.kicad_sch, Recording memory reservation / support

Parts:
C1011: RAM support value TBD; C_0603_1608Metric__C1011; Tolerance TBD; Voltage rating TBD; MPN TBD
C1012: RAM support value TBD; C_0603_1608Metric__C1012; Tolerance TBD; Voltage rating TBD; MPN TBD
C1013: RAM support value TBD; C_0603_1608Metric__C1013; Tolerance TBD; Voltage rating TBD; MPN TBD
C1014: RAM support value TBD; C_0603_1608Metric__C1014; Tolerance TBD; Voltage rating TBD; MPN TBD
C1015: RAM support value TBD; C_0603_1608Metric__C1015; Tolerance TBD; Voltage rating TBD; MPN TBD
C1016: RAM support value TBD; C_0603_1608Metric__C1016; Tolerance TBD; Voltage rating TBD; MPN TBD
C1017: RAM support value TBD; C_0603_1608Metric__C1017; Tolerance TBD; Voltage rating TBD; MPN TBD
C1018: RAM support value TBD; C_0603_1608Metric__C1018; Tolerance TBD; Voltage rating TBD; MPN TBD
C1019: RAM support value TBD; C_0603_1608Metric__C1019; Tolerance TBD; Voltage rating TBD; MPN TBD
C1020: RAM support value TBD; C_0603_1608Metric__C1020; Tolerance TBD; Voltage rating TBD; MPN TBD
C1021: RAM support value TBD; C_0603_1608Metric__C1021; Tolerance TBD; Voltage rating TBD; MPN TBD
C1022: RAM support value TBD; C_0603_1608Metric__C1022; Tolerance TBD; Voltage rating TBD; MPN TBD
R926: RAM support value TBD; R_0402_1005Metric__R926; Tolerance TBD; Voltage rating TBD; MPN TBD
R927: RAM support value TBD; R_0402_1005Metric__R927; Tolerance TBD; Voltage rating TBD; MPN TBD
R928: RAM support value TBD; R_0402_1005Metric__R928; Tolerance TBD; Voltage rating TBD; MPN TBD
R929: RAM support value TBD; R_0402_1005Metric__R929; Tolerance TBD; Voltage rating TBD; MPN TBD

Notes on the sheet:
GLOBAL LABELS ARE ELECTRICAL CONNECTIONS. TBD values are unresolved parts. DNP positions are optional or isolation provisions; open pins
Recording memory reservation / support
remain visible to ERC.

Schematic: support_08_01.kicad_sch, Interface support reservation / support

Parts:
C1101: Interface/filter capacitance TBD; C_0603_1608Metric__C1101; Tolerance TBD; Voltage rating TBD; MPN TBD
C1102: Interface/filter capacitance TBD; C_0603_1608Metric__C1102; Tolerance TBD; Voltage rating TBD; MPN TBD
C1103: Interface/filter capacitance TBD; C_0603_1608Metric__C1103; Tolerance TBD; Voltage rating TBD; MPN TBD

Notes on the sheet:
GLOBAL LABELS ARE ELECTRICAL CONNECTIONS. TBD values are unresolved parts. DNP positions are optional or isolation provisions; open pins
Interface support reservation / support
remain visible to ERC.

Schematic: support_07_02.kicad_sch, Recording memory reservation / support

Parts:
R930: RAM support value TBD; R_0402_1005Metric__R930; Tolerance TBD; Voltage rating TBD; MPN TBD
R931: RAM support value TBD; R_0402_1005Metric__R931; Tolerance TBD; Voltage rating TBD; MPN TBD
R932: RAM support value TBD; R_0402_1005Metric__R932; Tolerance TBD; Voltage rating TBD; MPN TBD
R933: RAM support value TBD; R_0402_1005Metric__R933; Tolerance TBD; Voltage rating TBD; MPN TBD

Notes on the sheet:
GLOBAL LABELS ARE ELECTRICAL CONNECTIONS. TBD values are unresolved parts. DNP positions are optional or isolation provisions; open pins
Recording memory reservation / support
remain visible to ERC.

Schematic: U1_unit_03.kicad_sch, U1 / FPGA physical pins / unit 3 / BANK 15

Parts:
U1: XC7A200T-1SBG484C; Xilinx_SBG484__U1; Tolerance TBD; Voltage rating TBD; MPN XC7A200T-1SBG484C

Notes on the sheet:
bank plan or timing constraints.
U1 / FPGA physical pins / unit 3 / BANK 15
Exact XC7A200T SBG484 physical pin map. Boot and core rails are drafted. Unassigned acquisition/link/DDR pins remain open; no completed

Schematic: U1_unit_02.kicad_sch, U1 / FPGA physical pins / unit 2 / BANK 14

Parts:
U1: XC7A200T-1SBG484C; Xilinx_SBG484__U1; Tolerance TBD; Voltage rating TBD; MPN XC7A200T-1SBG484C

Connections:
PUDC_B: U1.U22 (IO_L3P_T0_DQS_PUDC_B_14); also elsewhere on the board
QSPI_CS_N: U1.T19 (IO_L6P_T0_FCS_B_14); also elsewhere on the board
QSPI_IO0_FPGA: U1.P22 (IO_L1P_T0_D00_MOSI_14); also elsewhere on the board
QSPI_IO1_FPGA: U1.R22 (IO_L1N_T0_D01_DIN_14); also elsewhere on the board
QSPI_IO2_FPGA: U1.P21 (IO_L2P_T0_D02_14); also elsewhere on the board
QSPI_IO3_FPGA: U1.R21 (IO_L2N_T0_D03_14); also elsewhere on the board

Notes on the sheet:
bank plan or timing constraints.
U1 / FPGA physical pins / unit 2 / BANK 14
Exact XC7A200T SBG484 physical pin map. Boot and core rails are drafted. Unassigned acquisition/link/DDR pins remain open; no completed

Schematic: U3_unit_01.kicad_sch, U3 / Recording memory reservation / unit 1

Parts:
U3: Recording RAM / exact part TBD; Micron_FBGA-96_8x14mm_Layout9x16_P0.8mm__U3; Tolerance TBD; Voltage rating TBD; MPN TBD

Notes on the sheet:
are not an approved DDR netlist.
ONE recording-RAM package reservation. Exact device, capacity, signal map, controller and supply/termination requirements TBD. Pad numbers
U3 / Recording memory reservation / unit 1

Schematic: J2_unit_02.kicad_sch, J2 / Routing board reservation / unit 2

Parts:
J2: Routing 80-contact / proxy; Hirose_DF40C-80DS-0.4V_2x40_P0.4mm__J2; Tolerance TBD; Voltage rating TBD; MPN TBD

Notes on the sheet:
J2 / Routing board reservation / unit 2
and Gerald.
Routing-to-FPGA connector SPACE RESERVATION B. Coordinate carrier revision, grounds, clock/control sharing and power handoff with Zitong

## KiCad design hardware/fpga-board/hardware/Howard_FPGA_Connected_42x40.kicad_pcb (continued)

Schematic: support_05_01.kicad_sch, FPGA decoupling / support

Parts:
C1: 680uF; CP_EIA-7343-43_Kemet-X__C1; Tolerance TBD; Voltage rating TBD; MPN TBD
C2: 4.7uF; C_0402_1005Metric__C2; Tolerance 10%; Voltage rating 10 V; MPN C1005X5R1A475K050BC
C3: 4.7uF; C_0402_1005Metric__C3; Tolerance 10%; Voltage rating 10 V; MPN C1005X5R1A475K050BC
C4: 4.7uF; C_0402_1005Metric__C4; Tolerance 10%; Voltage rating 10 V; MPN C1005X5R1A475K050BC
C5: 4.7uF; C_0402_1005Metric__C5; Tolerance 10%; Voltage rating 10 V; MPN C1005X5R1A475K050BC
C6: 4.7uF; C_0402_1005Metric__C6; Tolerance 10%; Voltage rating 10 V; MPN C1005X5R1A475K050BC
C7: 4.7uF; C_0402_1005Metric__C7; Tolerance 10%; Voltage rating 10 V; MPN C1005X5R1A475K050BC
C8: 4.7uF; C_0402_1005Metric__C8; Tolerance 10%; Voltage rating 10 V; MPN C1005X5R1A475K050BC
C9: 4.7uF; C_0402_1005Metric__C9; Tolerance 10%; Voltage rating 10 V; MPN C1005X5R1A475K050BC
C10: 4.7uF; C_0402_1005Metric__C10; Tolerance 10%; Voltage rating 10 V; MPN C1005X5R1A475K050BC
C11: 4.7uF; C_0402_1005Metric__C11; Tolerance 10%; Voltage rating 10 V; MPN C1005X5R1A475K050BC
C12: 4.7uF; C_0402_1005Metric__C12; Tolerance 10%; Voltage rating 10 V; MPN C1005X5R1A475K050BC
C13: 4.7uF; C_0402_1005Metric__C13; Tolerance 10%; Voltage rating 10 V; MPN C1005X5R1A475K050BC
C14: 0.47uF; C_0201_0603Metric__C14; Tolerance 20%; Voltage rating 10 V; MPN C0603X5R1A474M030BC
C15: 0.47uF; C_0201_0603Metric__C15; Tolerance 20%; Voltage rating 10 V; MPN C0603X5R1A474M030BC
C16: 0.47uF; C_0201_0603Metric__C16; Tolerance 20%; Voltage rating 10 V; MPN C0603X5R1A474M030BC

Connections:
+1V0: C1.1, C2.1, C3.1, C4.1, C5.1, C6.1, C7.1, C8.1, C9.1, C10.1, C11.1, C12.1, C13.1, C14.1, C15.1, C16.1; also elsewhere on the board
GND: C1.2, C2.2, C3.2, C4.2, C5.2, C6.2, C7.2, C8.2, C9.2, C10.2, C11.2, C12.2, C13.2, C14.2, C15.2, C16.2; also elsewhere on the board

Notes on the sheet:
GLOBAL LABELS ARE ELECTRICAL CONNECTIONS. TBD values are unresolved parts. DNP positions are optional or isolation provisions; open pins
FPGA decoupling / support
remain visible to ERC.

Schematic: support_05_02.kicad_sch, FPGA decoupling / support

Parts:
C17: 0.47uF; C_0201_0603Metric__C17; Tolerance 20%; Voltage rating 10 V; MPN C0603X5R1A474M030BC
C18: 0.47uF; C_0201_0603Metric__C18; Tolerance 20%; Voltage rating 10 V; MPN C0603X5R1A474M030BC
C19: 0.47uF; C_0201_0603Metric__C19; Tolerance 20%; Voltage rating 10 V; MPN C0603X5R1A474M030BC
C20: 0.47uF; C_0201_0603Metric__C20; Tolerance 20%; Voltage rating 10 V; MPN C0603X5R1A474M030BC
C21: 0.47uF; C_0201_0603Metric__C21; Tolerance 20%; Voltage rating 10 V; MPN C0603X5R1A474M030BC
C22: 0.47uF; C_0201_0603Metric__C22; Tolerance 20%; Voltage rating 10 V; MPN C0603X5R1A474M030BC
C23: 0.47uF; C_0201_0603Metric__C23; Tolerance 20%; Voltage rating 10 V; MPN C0603X5R1A474M030BC
C24: 0.47uF; C_0201_0603Metric__C24; Tolerance 20%; Voltage rating 10 V; MPN C0603X5R1A474M030BC
C25: 0.47uF; C_0201_0603Metric__C25; Tolerance 20%; Voltage rating 10 V; MPN C0603X5R1A474M030BC
C26: 0.47uF; C_0201_0603Metric__C26; Tolerance 20%; Voltage rating 10 V; MPN C0603X5R1A474M030BC
C27: 0.47uF; C_0201_0603Metric__C27; Tolerance 20%; Voltage rating 10 V; MPN C0603X5R1A474M030BC
C28: 100uF; C_1210_3225Metric__C28; Tolerance TBD; Voltage rating TBD; MPN TBD
C29: 0.47uF; C_0201_0603Metric__C29; Tolerance 20%; Voltage rating 10 V; MPN C0603X5R1A474M030BC
C30: 0.47uF; C_0201_0603Metric__C30; Tolerance 20%; Voltage rating 10 V; MPN C0603X5R1A474M030BC
C31: 0.47uF; C_0201_0603Metric__C31; Tolerance 20%; Voltage rating 10 V; MPN C0603X5R1A474M030BC
C32: 47uF; C_1210_3225Metric__C32; Tolerance TBD; Voltage rating TBD; MPN TBD

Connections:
+1V0: C17.1, C18.1, C19.1, C20.1, C21.1, C22.1, C23.1, C24.1, C25.1, C26.1, C27.1, C28.1, C29.1, C30.1, C31.1; also elsewhere on the board
+1V8: C32.1; also elsewhere on the board
GND: C17.2, C18.2, C19.2, C20.2, C21.2, C22.2, C23.2, C24.2, C25.2, C26.2, C27.2, C28.2, C29.2, C30.2, C31.2, C32.2; also elsewhere on the board

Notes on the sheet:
GLOBAL LABELS ARE ELECTRICAL CONNECTIONS. TBD values are unresolved parts. DNP positions are optional or isolation provisions; open pins
FPGA decoupling / support
remain visible to ERC.

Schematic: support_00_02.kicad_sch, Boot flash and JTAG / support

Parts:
C101: 100nF; C_0402_1005Metric__C101; Tolerance 10%; Voltage rating 16 V; MPN C1005X7R1C104K050BC
C102: 1uF; C_0402_1005Metric__C102; Tolerance 10%; Voltage rating 35 V; MPN C1005X5R1V105K050BC
R115: 0Ohm; R_0201_0603Metric__R115; Tolerance jumper <=50mOhm; Voltage rating 30 V limiting voltage; MPN CRCW02010000Z0ED

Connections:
+3V3: C101.1, C102.1; also elsewhere on the board
GND: C101.2, C102.2; also elsewhere on the board
QSPI_IO3: R115.2; also elsewhere on the board
QSPI_IO3_FPGA: R115.1; also elsewhere on the board

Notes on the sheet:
GLOBAL LABELS ARE ELECTRICAL CONNECTIONS. TBD values are unresolved parts. DNP positions are optional or isolation provisions; open pins
Boot flash and JTAG / support
remain visible to ERC.

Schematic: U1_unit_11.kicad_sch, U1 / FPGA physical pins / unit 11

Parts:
U1: XC7A200T-1SBG484C; Xilinx_SBG484__U1; Tolerance TBD; Voltage rating TBD; MPN XC7A200T-1SBG484C

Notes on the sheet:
U1 / FPGA physical pins / unit 11
bank plan or timing constraints.
Exact XC7A200T SBG484 physical pin map. Boot and core rails are drafted. Unassigned acquisition/link/DDR pins remain open; no completed

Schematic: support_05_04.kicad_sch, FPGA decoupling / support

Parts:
C49: 4.7uF; C_0402_1005Metric__C49; Tolerance 10%; Voltage rating 10 V; MPN C1005X5R1A475K050BC
C50: 4.7uF; C_0402_1005Metric__C50; Tolerance 10%; Voltage rating 10 V; MPN C1005X5R1A475K050BC
C51: 0.47uF; C_0201_0603Metric__C51; Tolerance 20%; Voltage rating 10 V; MPN C0603X5R1A474M030BC
C52: 0.47uF; C_0201_0603Metric__C52; Tolerance 20%; Voltage rating 10 V; MPN C0603X5R1A474M030BC
C53: 0.47uF; C_0201_0603Metric__C53; Tolerance 20%; Voltage rating 10 V; MPN C0603X5R1A474M030BC
C54: 0.47uF; C_0201_0603Metric__C54; Tolerance 20%; Voltage rating 10 V; MPN C0603X5R1A474M030BC
C55: 47uF; C_1210_3225Metric__C55; Tolerance TBD; Voltage rating TBD; MPN TBD
C56: 4.7uF; C_0402_1005Metric__C56; Tolerance 10%; Voltage rating 10 V; MPN C1005X5R1A475K050BC
C57: 4.7uF; C_0402_1005Metric__C57; Tolerance 10%; Voltage rating 10 V; MPN C1005X5R1A475K050BC
C58: 0.47uF; C_0201_0603Metric__C58; Tolerance 20%; Voltage rating 10 V; MPN C0603X5R1A474M030BC
C59: 0.47uF; C_0201_0603Metric__C59; Tolerance 20%; Voltage rating 10 V; MPN C0603X5R1A474M030BC
C60: 0.47uF; C_0201_0603Metric__C60; Tolerance 20%; Voltage rating 10 V; MPN C0603X5R1A474M030BC
C61: 0.47uF; C_0201_0603Metric__C61; Tolerance 20%; Voltage rating 10 V; MPN C0603X5R1A474M030BC
C62: 47uF; C_1210_3225Metric__C62; Tolerance TBD; Voltage rating TBD; MPN TBD
C63: 4.7uF; C_0402_1005Metric__C63; Tolerance 10%; Voltage rating 10 V; MPN C1005X5R1A475K050BC
C64: 4.7uF; C_0402_1005Metric__C64; Tolerance 10%; Voltage rating 10 V; MPN C1005X5R1A475K050BC

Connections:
+3V3: C49.1, C50.1, C51.1, C52.1, C53.1, C54.1, C55.1; also elsewhere on the board
GND: C49.2, C50.2, C51.2, C52.2, C53.2, C54.2, C55.2, C56.2, C57.2, C58.2, C59.2, C60.2, C61.2, C62.2, C63.2, C64.2; also elsewhere on the board
VCCO_15_TBD: C56.1, C57.1, C58.1, C59.1, C60.1, C61.1, C62.1; also elsewhere on the board
VCCO_16_TBD: C63.1, C64.1; also elsewhere on the board

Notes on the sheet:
GLOBAL LABELS ARE ELECTRICAL CONNECTIONS. TBD values are unresolved parts. DNP positions are optional or isolation provisions; open pins
FPGA decoupling / support
remain visible to ERC.

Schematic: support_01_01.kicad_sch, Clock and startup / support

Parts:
C120: TBD oscillator bypass; C_0603_1608Metric__C120; Tolerance TBD; Voltage rating TBD; MPN TBD
R120: TBD clock series resistor; R_0402_1005Metric__R120; Tolerance TBD; Voltage rating TBD; MPN TBD
R121: TBD oscillator control resistor; R_0402_1005Metric__R121; Tolerance TBD; Voltage rating TBD; MPN TBD
Y1: Oscillator frequency / MPN TBD; Oscillator_SMD_Abracon_ASE-4Pin_3.2x2.5mm__Y1; Tolerance TBD; Voltage rating TBD; MPN TBD

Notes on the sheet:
GLOBAL LABELS ARE ELECTRICAL CONNECTIONS. TBD values are unresolved parts. DNP positions are optional or isolation provisions; open pins
remain visible to ERC.
Clock and startup / support

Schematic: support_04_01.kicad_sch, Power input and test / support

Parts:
F1: FUSE / rating TBD; Fuse_1206_3216Metric__F1; Tolerance TBD; Voltage rating TBD; MPN TBD
J5: DC INPUT / 12V proposal; JST_PH_B2B-PH-K_1x02_P2.00mm_Vertical__J5; Tolerance TBD; Voltage rating TBD; MPN TBD
TP1: GND; TestPoint_Pad_D1.0mm__TP1; Tolerance TBD; Voltage rating TBD; MPN PCB copper test pad
TP2: VIN_PROTECTED; TestPoint_Pad_D1.0mm__TP2; Tolerance TBD; Voltage rating TBD; MPN PCB copper test pad
TP3: +1V0; TestPoint_Pad_D1.0mm__TP3; Tolerance TBD; Voltage rating TBD; MPN PCB copper test pad
TP4: +1V8; TestPoint_Pad_D1.0mm__TP4; Tolerance TBD; Voltage rating TBD; MPN PCB copper test pad
TP5: +1V5; TestPoint_Pad_D1.0mm__TP5; Tolerance TBD; Voltage rating TBD; MPN PCB copper test pad
TP6: +3V3; TestPoint_Pad_D1.0mm__TP6; Tolerance TBD; Voltage rating TBD; MPN PCB copper test pad
TP7: PROGRAM_B; TestPoint_Pad_D1.0mm__TP7; Tolerance TBD; Voltage rating TBD; MPN PCB copper test pad
TP8: DONE; TestPoint_Pad_D1.0mm__TP8; Tolerance TBD; Voltage rating TBD; MPN PCB copper test pad

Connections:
+1V0: TP3.1; also elsewhere on the board
+1V5: TP5.1; also elsewhere on the board
+1V8: TP4.1; also elsewhere on the board
+3V3: TP6.1; also elsewhere on the board
DONE: TP8.1; also elsewhere on the board
GND: J5.2, TP1.1; also elsewhere on the board
PROGRAM_B: TP7.1; also elsewhere on the board
VIN_PROTECTED: F1.2, TP2.1; also elsewhere on the board
VIN_RAW: F1.1, J5.1

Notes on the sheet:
GLOBAL LABELS ARE ELECTRICAL CONNECTIONS. TBD values are unresolved parts. DNP positions are optional or isolation provisions; open pins
Power input and test / support
remain visible to ERC.

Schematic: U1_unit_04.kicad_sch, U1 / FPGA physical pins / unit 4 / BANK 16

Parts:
U1: XC7A200T-1SBG484C; Xilinx_SBG484__U1; Tolerance TBD; Voltage rating TBD; MPN XC7A200T-1SBG484C

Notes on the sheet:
U1 / FPGA physical pins / unit 4 / BANK 16
bank plan or timing constraints.
Exact XC7A200T SBG484 physical pin map. Boot and core rails are drafted. Unassigned acquisition/link/DDR pins remain open; no completed

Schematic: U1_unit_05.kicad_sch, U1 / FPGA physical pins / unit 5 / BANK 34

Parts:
U1: XC7A200T-1SBG484C; Xilinx_SBG484__U1; Tolerance TBD; Voltage rating TBD; MPN XC7A200T-1SBG484C

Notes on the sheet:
bank plan or timing constraints.
Exact XC7A200T SBG484 physical pin map. Boot and core rails are drafted. Unassigned acquisition/link/DDR pins remain open; no completed
U1 / FPGA physical pins / unit 5 / BANK 34

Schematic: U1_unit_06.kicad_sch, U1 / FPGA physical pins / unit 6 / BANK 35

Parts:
U1: XC7A200T-1SBG484C; Xilinx_SBG484__U1; Tolerance TBD; Voltage rating TBD; MPN XC7A200T-1SBG484C

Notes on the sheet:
bank plan or timing constraints.
U1 / FPGA physical pins / unit 6 / BANK 35
Exact XC7A200T SBG484 physical pin map. Boot and core rails are drafted. Unassigned acquisition/link/DDR pins remain open; no completed

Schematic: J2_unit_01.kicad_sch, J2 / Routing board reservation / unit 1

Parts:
J2: Routing 80-contact / proxy; Hirose_DF40C-80DS-0.4V_2x40_P0.4mm__J2; Tolerance TBD; Voltage rating TBD; MPN TBD

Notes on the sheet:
and Gerald.
J2 / Routing board reservation / unit 1
Routing-to-FPGA connector SPACE RESERVATION B. Coordinate carrier revision, grounds, clock/control sharing and power handoff with Zitong

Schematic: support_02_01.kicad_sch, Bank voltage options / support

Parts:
R130: 0R / DNP; R_0402_1005Metric__R130; Tolerance TBD; Voltage rating TBD; MPN TBD; not fitted
R131: 0R / DNP; R_0402_1005Metric__R131; Tolerance TBD; Voltage rating TBD; MPN TBD; not fitted
R132: 0R / DNP; R_0402_1005Metric__R132; Tolerance TBD; Voltage rating TBD; MPN TBD; not fitted
R133: 0R / DNP; R_0402_1005Metric__R133; Tolerance TBD; Voltage rating TBD; MPN TBD; not fitted
R134: 0R / DNP; R_0402_1005Metric__R134; Tolerance TBD; Voltage rating TBD; MPN TBD; not fitted

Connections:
+1V5: R131.1, R132.1, R133.1, R134.1; also elsewhere on the board
+3V3: R130.1; also elsewhere on the board
VCCO_13_TBD: R130.2; also elsewhere on the board
VCCO_15_TBD: R131.2; also elsewhere on the board
VCCO_16_TBD: R132.2; also elsewhere on the board
VCCO_34_TBD: R133.2; also elsewhere on the board
VCCO_35_TBD: R134.2; also elsewhere on the board

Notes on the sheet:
GLOBAL LABELS ARE ELECTRICAL CONNECTIONS. TBD values are unresolved parts. DNP positions are optional or isolation provisions; open pins
Bank voltage options / support
remain visible to ERC.

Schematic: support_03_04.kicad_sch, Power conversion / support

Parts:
C319: 100uF 6.3V local-output PROVISIONAL; C_1210_3225Metric__C319; Tolerance TBD; Voltage rating TBD; MPN TBD
C320: 100uF 6.3V local-output PROVISIONAL; C_1210_3225Metric__C320; Tolerance TBD; Voltage rating TBD; MPN TBD
C321: 47uF 6.3V local-output PROVISIONAL; C_1210_3225Metric__C321; Tolerance TBD; Voltage rating TBD; MPN TBD
C322: 47uF 6.3V local-output PROVISIONAL; C_1210_3225Metric__C322; Tolerance TBD; Voltage rating TBD; MPN TBD
C323: 47uF 6.3V local-output PROVISIONAL; C_1210_3225Metric__C323; Tolerance TBD; Voltage rating TBD; MPN TBD
C324: 22uF 6.3V local-output PROVISIONAL; C_1210_3225Metric__C324; Tolerance TBD; Voltage rating TBD; MPN TBD
C325: 22uF 6.3V local-output PROVISIONAL; C_1210_3225Metric__C325; Tolerance TBD; Voltage rating TBD; MPN TBD
C326: 22uF 6.3V local-output PROVISIONAL; C_1210_3225Metric__C326; Tolerance TBD; Voltage rating TBD; MPN TBD
C327: 22uF 6.3V local-output PROVISIONAL; C_1210_3225Metric__C327; Tolerance TBD; Voltage rating TBD; MPN TBD

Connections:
+1V0: C319.1, C320.1; also elsewhere on the board
+1V5: C324.1, C325.1; also elsewhere on the board
+1V8: C321.1, C322.1, C323.1; also elsewhere on the board
+3V3: C326.1, C327.1; also elsewhere on the board
GND: C319.2, C320.2, C321.2, C322.2, C323.2, C324.2, C325.2, C326.2, C327.2; also elsewhere on the board

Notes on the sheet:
GLOBAL LABELS ARE ELECTRICAL CONNECTIONS. TBD values are unresolved parts. DNP positions are optional or isolation provisions; open pins
Power conversion / support
remain visible to ERC.

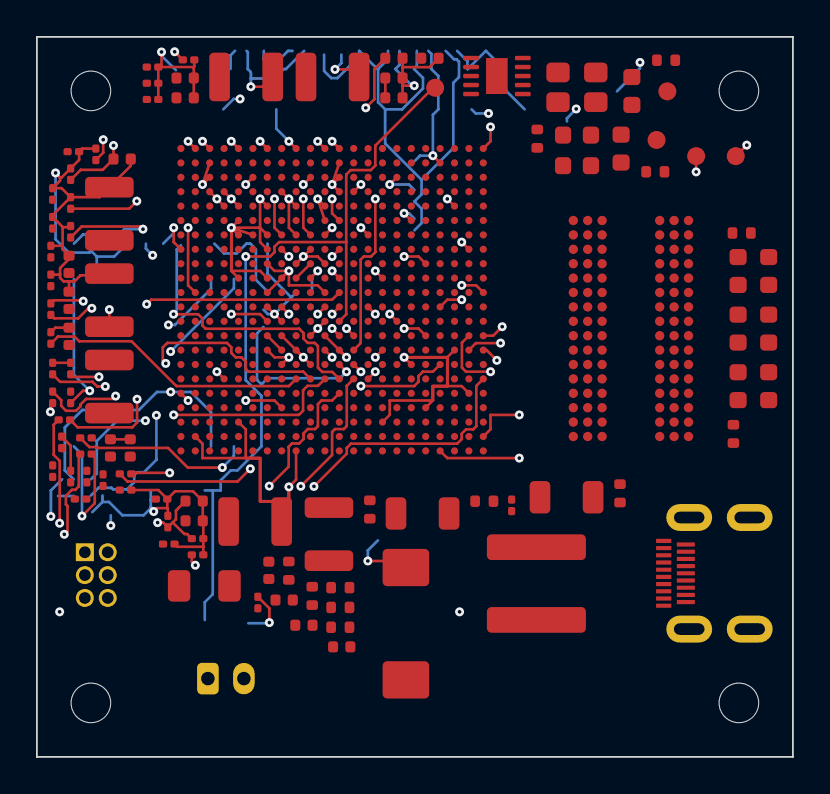
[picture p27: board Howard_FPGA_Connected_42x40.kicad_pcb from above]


Board: 8 copper layers, 42.0 x 40.0 mm, 214 parts (108 on the bottom side), 65 nets.

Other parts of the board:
J3: Micro-HDMI / custom-link pinout TBD; HDMI_Micro-D_Molex_46765-1xxx__J3

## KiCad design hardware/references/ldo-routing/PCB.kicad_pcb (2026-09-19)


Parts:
C1, C6, C7, C11, C15, C18, C19, C22, C27: 1uF; C_0603_1608Metric
C2, C3, C4, C5, C8, C9, C10, C12, C13, C14, C16, C17, C20, C21, C23, C24, C25, C28: 10uF; C_0603_1608Metric
C26, C29, C30, C31, C32, C33, C34, C35, C36, C37, C38, C39, C40, C41, C42, C43: 10uF; C_0201_0603Metric
J1: Conn_02x25_Odd_Even; Hirose_DF40C-50DP-0.4V_2x25-1MP_P0.4mm
J2: Conn_02x25_Odd_Even; HRS_DF40C-50DS-0.4V(Correct Orientation)
J3, J4, J5, J6, J7, J8, J9, J10, J11, J12, J13, J14, J15, J16, J17, J18: Conn_01x01_Pin; PinHeader_1x01_P1.00mm_Horizontal
R1: 7.5k; C_0603_1608Metric
R2: 16k; C_0603_1608Metric
R3, R4, R5, R6, R7: 15k; C_0603_1608Metric
R8, R9: 90k; C_0603_1608Metric
U1, U2, U3, U4, U5, U6, U7, U8, U9: LT3042xMSE; DFN-10-1EP_3x3mm_P0.5mm_EP1.65x2.38mm

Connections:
3V3: C3.1, C5.1, C9.1, C13.1, C17.1, C21.1, C25.1, J1.1, J1.2, U1.1 (IN), U1.2 (IN), U1.3 (EN/UV), U1.6 (PGFB), U2.1 (IN), U2.2 (IN), U2.3 (EN/UV), U2.6 (PGFB), U3.1 (IN), U3.2 (IN), U3.3 (EN/UV), U3.6 (PGFB), U4.1 (IN), U4.2 (IN), U4.3 (EN/UV), U4.6 (PGFB), U5.1 (IN), U5.2 (IN), U5.3 (EN/UV), U5.6 (PGFB), U6.1 (IN), U6.2 (IN), U6.3 (EN/UV), U6.6 (PGFB), U7.1 (IN), U7.2 (IN), U7.3 (EN/UV), U7.6 (PGFB)
/AC_IN: J2.39, J18.1
/AGND: C1.2, C2.2, C3.2, C4.2, C7.2, C9.2, C10.2, C11.2, C12.2, C13.2, C14.1, C15.2, C16.2, C17.2, C19.2, C20.2, C21.2, C22.2, C24.2, C25.2, C26.2, C27.2, C28.2, C29.2, C30.2, C31.2, C32.2, C33.2, C34.2, C35.2, C36.2, C37.2, C38.2, C39.2, C40.2, C41.2, C42.2, C43.2, J2.4, J2.20, J2.22, J2.23, J2.32, J2.34, J2.48, J17.1, R1.2, R2.2, R3.2, R4.2, R6.2, R7.2, R9.2, U1.5 (ILIM), U1.8 (GND), U1.11 (GND), U3.5 (ILIM), U3.8 (GND), U3.11 (GND), U4.5 (ILIM), U4.8 (GND), U4.11 (GND), U5.5 (ILIM), U5.8 (GND), U5.11 (GND), U6.5 (ILIM), U6.8 (GND), U6.11 (GND), U7.5 (ILIM), U7.8 (GND), U7.11 (GND), U8.5 (ILIM), U8.8 (GND), U8.11 (GND), U9.1 (IN), U9.2 (IN), U9.3 (EN/UV), U9.6 (PGFB)
/CHIP_RESET: J1.14, J2.41
/CLK32MHZ: J1.36, J2.11, J14.1
/CLKH: J1.12, J2.50
/D<1>: J1.4, J2.49, J9.1
/D<2>: J1.6, J2.47, J10.1
/D<3>: J1.8, J2.45, J11.1
/D<4>: J1.10, J2.43, J12.1
/D<5>: J1.38, J2.9, J3.1
/D<6>: J1.40, J2.7, J4.1
/D<7>: J1.42, J2.5, J5.1
/D<8>: J1.44, J2.3, J6.1
/DGND: C5.2, C6.2, C8.2, J1.49, J1.50, J2.24, J2.26, J2.28, J2.30, J16.1, R5.2, U2.5 (ILIM), U2.8 (GND), U2.11 (GND)
/DISC_OUT: J2.2
/DVDD: C16.1, J2.14, J2.16, U4.9 (OUTS), U4.10 (OUT)
/FE_RESET: J1.20, J2.35
/IMP_TEST: J1.18, J2.37
/INPUT_VDD10: C2.1, J15.1, U8.1 (IN), U8.2 (IN), U8.3 (EN/UV), U8.6 (PGFB)
/INPUT_VSS10: C14.2, C18.2, C23.2, J8.1, R8.2, U9.5 (ILIM), U9.8 (GND), U9.11 (GND)
/READ: J1.46, J2.1, J7.1
/REF_VCM: C28.1, J2.40, U7.9 (OUTS), U7.10 (OUT)
/REF_VDD: C20.1, C26.1, C33.1, C42.1, C43.1, J2.18, J2.36, U5.9 (OUTS), U5.10 (OUT)
/SPI_CLK: J1.22, J2.33
/SPI_DINL: J1.26, J2.29
/SPI_DINR: J1.28, J2.27
/SPI_LATCH: J1.24, J2.31
/STIM_CHB: J1.33, J2.15
/STIM_CLK: J1.29, J2.19
/STIM_EN: J1.31, J2.17
/STIM_START: J1.27, J2.21
/SYNC: J1.34, J2.13, J13.1
/VCC: J1.47, J1.48
/VDD10: C10.1, J2.46, U8.9 (OUTS), U8.10 (OUT)
/VDD_ADC: C8.1, C31.1, C32.1, C38.1, C39.1, J2.10, J2.42, U2.9 (OUTS), U2.10 (OUT)
/VDD_CGEN: C24.1, J2.25, U6.9 (OUTS), U6.10 (OUT)
/VDD_DRIVER: C12.1, C34.1, C35.1, C36.1, C37.1, J2.8, J2.44, U3.9 (OUTS), U3.10 (OUT)
/VDD_FE: C4.1, C29.1, C30.1, C40.1, C41.1, J2.12, J2.38, U1.9 (OUTS), U1.10 (OUT)
/VSS10: C23.1, J2.6, U9.9 (OUTS), U9.10 (OUT)
unnamed: C1.1, R4.1, U1.7 (SET)
unnamed: C6.1, R5.1, U2.7 (SET)
unnamed: C11.1, R6.1, U3.7 (SET)
unnamed: C15.1, R3.1, U4.7 (SET)
unnamed: C19.1, R7.1, U5.7 (SET)
unnamed: C22.1, R2.1, U6.7 (SET)
unnamed: C27.1, R1.1, U7.7 (SET)
unnamed: C7.1, R9.1, U8.7 (SET)
unnamed: C18.1, R8.1, U9.7 (SET)



Board: 6 copper layers, 18.3 x 42.0 mm, 80 parts (30 on the bottom side), 48 nets.

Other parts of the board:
J1#2: DF40C-24DP

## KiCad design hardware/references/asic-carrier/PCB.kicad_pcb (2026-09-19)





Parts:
C1, C2, C3, C4, C5, C6, C7, C8, C9, C10, C11, C12, C13, C14, C15, C16, C17, C18, C19, C20, C21, C22, C23, C24, C25, C26, C27, C28, C29, C30, C31, C32, C33, C34, C35, C36, C37, C38, C39, C40, C41, C42, C43, C44, C45, C46, C47, C48, C49, C50: C_Small_US; C_0201_0603Metric
J1: Conn_01x01_Pin; PinHeader_1x01_P1.00mm_Horizontal
J3: Conn_02x40_Odd_Even; Hirose_DF40C-80DS-0.4V_2x40_P0.4mm
U01_BCD1, U01_BCD2: *; U01_BCD_OFF_CHIP

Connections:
/AC_IN: J3.69, U01_BCD1.AC_IN, U01_BCD2.AC_IN
/AGND: C1.2, C2.2, C3.2, C4.2, C5.2, C6.2, C15.2, C16.2, C17.2, C18.2, C19.2, C20.2, C21.2, C22.2, C23.2, C24.2, C25.2, C26.2, C27.2, C28.2, C29.2, C30.2, C31.2, C32.2, C33.2, C34.2, C35.2, C36.2, C37.2, C38.2, C39.2, C40.2, C41.2, C42.2, C43.2, C44.2, C45.2, C46.2, C47.2, C48.2, C49.2, C50.2, J1.1 (Pin_1_1), J3.42, J3.44, U01_BCD1.AGND2, U01_BCD1.AGND_1, U01_BCD1.LAGND_1, U01_BCD1.LAGND_2, U01_BCD1.LAGND_3, U01_BCD1.LAGND_4, U01_BCD1.LAGND_5, U01_BCD1.LAGND_6, U01_BCD1.LAGND_7, U01_BCD1.LAGND_8, U01_BCD1.LAGND_9, U01_BCD1.LAGND_10, U01_BCD1.LAGND_11, U01_BCD1.LAGND_12, U01_BCD1.LAGND_13, U01_BCD1.LAGND_14, U01_BCD1.LAGND_15, U01_BCD1.LREF_GND1, U01_BCD1.LREF_GND2, U01_BCD1.LREF_GND3, U01_BCD1.LREF_GND4, U01_BCD1.RAGND_1, U01_BCD1.RAGND_2, U01_BCD1.RAGND_3, U01_BCD1.RAGND_4, U01_BCD1.RAGND_5, U01_BCD1.RAGND_6, U01_BCD1.RAGND_7, U01_BCD1.RAGND_8, U01_BCD1.RAGND_9, U01_BCD1.RAGND_10, U01_BCD1.RAGND_11, U01_BCD1.RAGND_12, U01_BCD1.RAGND_13, U01_BCD1.RAGND_14, U01_BCD1.RAGND_15, U01_BCD1.REF_1, U01_BCD1.REF_2, U01_BCD1.REF_3, U01_BCD1.REF_4, U01_BCD1.RREF_GND1, U01_BCD1.RREF_GND2, U01_BCD1.RREF_GND3, U01_BCD1.RREF_GND4, U01_BCD2.AGND2, U01_BCD2.AGND_1, U01_BCD2.LAGND_1, U01_BCD2.LAGND_2, U01_BCD2.LAGND_3, U01_BCD2.LAGND_4, U01_BCD2.LAGND_5, U01_BCD2.LAGND_6, U01_BCD2.LAGND_7, U01_BCD2.LAGND_8, U01_BCD2.LAGND_9, U01_BCD2.LAGND_10, U01_BCD2.LAGND_11, U01_BCD2.LAGND_12, U01_BCD2.LAGND_13, U01_BCD2.LAGND_14, U01_BCD2.LAGND_15, U01_BCD2.LREF_GND1, U01_BCD2.LREF_GND2, U01_BCD2.LREF_GND3, U01_BCD2.LREF_GND4, U01_BCD2.RAGND_1, U01_BCD2.RAGND_2, U01_BCD2.RAGND_3, U01_BCD2.RAGND_4, U01_BCD2.RAGND_5, U01_BCD2.RAGND_6, U01_BCD2.RAGND_7, U01_BCD2.RAGND_8, U01_BCD2.RAGND_9, U01_BCD2.RAGND_10, U01_BCD2.RAGND_11, U01_BCD2.RAGND_12, U01_BCD2.RAGND_13, U01_BCD2.RAGND_14, U01_BCD2.RAGND_15, U01_BCD2.REF_1, U01_BCD2.REF_2, U01_BCD2.REF_3, U01_BCD2.REF_4, U01_BCD2.RREF_GND1, U01_BCD2.RREF_GND2, U01_BCD2.RREF_GND3, U01_BCD2.RREF_GND4
/CHIP_RESET: J3.71, U01_BCD1.RRST_DIGITAL, U01_BCD1.RST_DRIVER, U01_BCD2.RRST_DIGITAL, U01_BCD2.RST_DRIVER
/CLK32MHZ: J3.45, U01_BCD1.CLK32MHZ
/CLK32MHZ(2): J3.19, U01_BCD2.CLK32MHZ
/CLKH: J3.7, U01_BCD1.CLKH, U01_BCD2.CLKH
/D<1>: J3.79, U01_BCD1.DATAL<4>
/D<1>(2): J3.33, U01_BCD2.DATAL<4>
/D<2>: J3.77, U01_BCD1.DATAL<3>
/D<2>(2): J3.31, U01_BCD2.DATAL<3>
/D<3>: J3.75, U01_BCD1.DATAL<2>
/D<3>(2): J3.29, U01_BCD2.DATAL<2>
/D<4>: J3.73, U01_BCD1.DATAL<1>
/D<4>(2): J3.27, U01_BCD2.DATAL<1>
/D<5>: J3.43, U01_BCD1.DATAR<4>
/D<5>(2): J3.17, U01_BCD2.DATAR<4>
/D<6>: J3.41, U01_BCD1.DATAR<3>
/D<6>(2): J3.15, U01_BCD2.DATAR<3>
/D<7>: J3.39, U01_BCD1.DATAR<2>
/D<7>(2): J3.13, U01_BCD2.DATAR<2>
/D<8>: J3.37, U01_BCD1.DATAR<1>
/D<8>(2): J3.11, U01_BCD2.DATAR<1>
/DGND: C7.2, C8.2, C9.2, C10.2, C11.2, C12.2, C13.2, C14.2, J3.46, J3.48, U01_BCD1.DGND1, U01_BCD1.DGND2, U01_BCD1.DGND3, U01_BCD1.DGND4, U01_BCD1.EN_LDO, U01_BCD1.LDGND_1, U01_BCD1.LDGND_2, U01_BCD1.LDGND_3, U01_BCD1.LDGND_4, U01_BCD1.LDGND_5, U01_BCD1.LDGND_6, U01_BCD1.LDGND_7, U01_BCD1.LDGND_8, U01_BCD1.LDGND_9, U01_BCD1.LDGND_10, U01_BCD1.LDGND_11, U01_BCD1.LDGND_12, U01_BCD1.LDGND_13, U01_BCD1.RDGND_1, U01_BCD1.RDGND_2, U01_BCD1.RDGND_3, U01_BCD1.RDGND_4, U01_BCD1.RDGND_5, U01_BCD1.RDGND_6, U01_BCD1.RDGND_7, U01_BCD1.RDGND_8, U01_BCD1.RDGND_9, U01_BCD1.RDGND_10, U01_BCD1.RDGND_11, U01_BCD1.RDGND_12, U01_BCD1.RDGND_13, U01_BCD2.DGND1, U01_BCD2.DGND2, U01_BCD2.DGND3, U01_BCD2.DGND4, U01_BCD2.EN_LDO, U01_BCD2.LDGND_1, U01_BCD2.LDGND_2, U01_BCD2.LDGND_3, U01_BCD2.LDGND_4, U01_BCD2.LDGND_5, U01_BCD2.LDGND_6, U01_BCD2.LDGND_7, U01_BCD2.LDGND_8, U01_BCD2.LDGND_9, U01_BCD2.LDGND_10, U01_BCD2.LDGND_11, U01_BCD2.LDGND_12, U01_BCD2.LDGND_13, U01_BCD2.RDGND_1, U01_BCD2.RDGND_2, U01_BCD2.RDGND_3, U01_BCD2.RDGND_4, U01_BCD2.RDGND_5, U01_BCD2.RDGND_6, U01_BCD2.RDGND_7, U01_BCD2.RDGND_8, U01_BCD2.RDGND_9, U01_BCD2.RDGND_10, U01_BCD2.RDGND_11, U01_BCD2.RDGND_12, U01_BCD2.RDGND_13
/DISC_OUT: J3.5, U01_BCD1.DISC_OUT
/DISC_OUT(2): J3.3, U01_BCD2.DISC_OUT
/DVDD: C7.1, C8.1, C9.1, C10.1, C11.1, C12.1, C13.1, C14.1, J3.34, U01_BCD1.CGEN_RST, U01_BCD1.LDVDD_B1, U01_BCD1.LDVDD_B2, U01_BCD1.LDVDD_B3, U01_BCD1.LDVDD_T1, U01_BCD1.LDVDD_T2, U01_BCD1.LDVDD_T3, U01_BCD1.RDVDD_B1, U01_BCD1.RDVDD_B2, U01_BCD1.RDVDD_B3, U01_BCD1.RDVDD_T1, U01_BCD1.RDVDD_T2, U01_BCD1.RDVDD_T3, U01_BCD1.SPI_LDO_O, U01_BCD1.SPI_LDO_P, U01_BCD1.SPI_LDO_P1, U01_BCD1.SPI_LDO_P2, U01_BCD2.CGEN_RST, U01_BCD2.LDVDD_B1, U01_BCD2.LDVDD_B2, U01_BCD2.LDVDD_B3, U01_BCD2.LDVDD_T1, U01_BCD2.LDVDD_T2, U01_BCD2.LDVDD_T3, U01_BCD2.RDVDD_B1, U01_BCD2.RDVDD_B2, U01_BCD2.RDVDD_B3, U01_BCD2.RDVDD_T1, U01_BCD2.RDVDD_T2, U01_BCD2.RDVDD_T3, U01_BCD2.SPI_LDO_O, U01_BCD2.SPI_LDO_P, U01_BCD2.SPI_LDO_P1, U01_BCD2.SPI_LDO_P2
/FE_RESET: J3.65, U01_BCD1.RST_FEL, U01_BCD1.RST_FER, U01_BCD2.RST_FEL, U01_BCD2.RST_FER
/IMP_TEST: J3.67, U01_BCD1.IMP_TST, U01_BCD2.IMP_TST
/READ: J3.35, U01_BCD1.READ
/READ(2): J3.9, U01_BCD2.READ
/REF_VCM: C5.1, C46.1, C47.1, C49.1, J3.40, U01_BCD1.LREF_VCM1, U01_BCD1.LREF_VCM2, U01_BCD1.LREF_VCM3, U01_BCD1.LREF_VCM4, U01_BCD1.RREF_VCM1, U01_BCD1.RREF_VCM2, U01_BCD1.RREF_VCM3, U01_BCD1.RREF_VCM4, U01_BCD1.VCM, U01_BCD2.LREF_VCM1, U01_BCD2.LREF_VCM2, U01_BCD2.LREF_VCM3, U01_BCD2.LREF_VCM4, U01_BCD2.RREF_VCM1, U01_BCD2.RREF_VCM2, U01_BCD2.RREF_VCM3, U01_BCD2.RREF_VCM4, U01_BCD2.VCM
/REF_VDD: C2.1, C27.1, C28.1, C29.1, C30.1, C31.1, C32.1, C33.1, J3.52, U01_BCD1.LREF_VDD1, U01_BCD1.LREF_VDD2, U01_BCD1.LREF_VDD3, U01_BCD1.LREF_VDD4, U01_BCD1.RREF_VDD1, U01_BCD1.RREF_VDD2, U01_BCD1.RREF_VDD3, U01_BCD1.RREF_VDD4, U01_BCD2.LREF_VDD1, U01_BCD2.LREF_VDD2, U01_BCD2.LREF_VDD3, U01_BCD2.LREF_VDD4, U01_BCD2.RREF_VDD1, U01_BCD2.RREF_VDD2, U01_BCD2.RREF_VDD3, U01_BCD2.RREF_VDD4
/SPI_CLK: J3.63, U01_BCD1.SPI_CLK, U01_BCD2.SPI_CLK
/SPI_DINL: J3.59, U01_BCD1.SPI_DINL
/SPI_DINL(2): J3.25, U01_BCD2.SPI_DINL
/SPI_DINR: J3.57, U01_BCD1.SPI_DINR
/SPI_DINR(2): J3.23, U01_BCD2.SPI_DINR
/SPI_LATCH: J3.61, U01_BCD1.SPI_LATCH, U01_BCD2.SPI_LATCH
/STIM_CHB: J3.49, U01_BCD1.FPGA_CHBL, U01_BCD1.FPGA_CHBR, U01_BCD2.FPGA_CHBL, U01_BCD2.FPGA_CHBR
/STIM_CLK: J3.53, U01_BCD1.FPGA_CLK, U01_BCD2.FPGA_CLK
/STIM_EN: J3.51, U01_BCD1.FPGA_EN, U01_BCD2.FPGA_EN
/STIM_START: J3.55, U01_BCD1.FPGA_START, U01_BCD2.FPGA_START
/SYNC: J3.47, U01_BCD1.SYNC
/SYNC(2): J3.21, U01_BCD2.SYNC
/VDD10: C15.1, C16.1, C17.1, C18.1, C19.1, C20.1, J3.36, U01_BCD1.P10_L, U01_BCD1.P10_R, U01_BCD2.P10_L, U01_BCD2.P10_R
/VDD_ADC: C1.1, C34.1, C35.1, C36.1, C37.1, C38.1, J3.56, U01_BCD1.LVDD_ADC1, U01_BCD1.LVDD_ADC2, U01_BCD1.LVDD_ADC3, U01_BCD1.LVDD_ADC4, U01_BCD1.LVDD_ADC5, U01_BCD1.RVDD_ADC1, U01_BCD1.RVDD_ADC2, U01_BCD1.RVDD_ADC3, U01_BCD1.RVDD_ADC4, U01_BCD1.RVDD_ADC5, U01_BCD2.LVDD_ADC1, U01_BCD2.LVDD_ADC2, U01_BCD2.LVDD_ADC3, U01_BCD2.LVDD_ADC4, U01_BCD2.LVDD_ADC5, U01_BCD2.RVDD_ADC1, U01_BCD2.RVDD_ADC2, U01_BCD2.RVDD_ADC3, U01_BCD2.RVDD_ADC4, U01_BCD2.RVDD_ADC5
/VDD_CGEN: C6.1, C50.1, J3.1, U01_BCD1.VDD_CGEN, U01_BCD2.VDD_CGEN
/VDD_DRIVER: C3.1, C39.1, C40.1, C41.1, C42.1, C43.1, J3.38, U01_BCD1.LVDD_DRIVER1, U01_BCD1.LVDD_DRIVER2, U01_BCD1.LVDD_DRIVER3, U01_BCD1.LVDD_DRIVER4, U01_BCD1.LVDD_DRIVER5, U01_BCD1.RVDD_DRIVER1, U01_BCD1.RVDD_DRIVER2, U01_BCD1.RVDD_DRIVER3, U01_BCD1.RVDD_DRIVER4, U01_BCD1.RVDD_DRIVER5, U01_BCD2.LVDD_DRIVER1, U01_BCD2.LVDD_DRIVER2, U01_BCD2.LVDD_DRIVER3, U01_BCD2.LVDD_DRIVER4, U01_BCD2.LVDD_DRIVER5, U01_BCD2.RVDD_DRIVER1, U01_BCD2.RVDD_DRIVER2, U01_BCD2.RVDD_DRIVER3, U01_BCD2.RVDD_DRIVER4, U01_BCD2.RVDD_DRIVER5
/VDD_FE: C4.1, C44.1, C45.1, C48.1, J3.50, U01_BCD1.LVDD_FE1, U01_BCD1.LVDD_FE2, U01_BCD1.LVDD_FE3, U01_BCD1.LVDD_FE4, U01_BCD1.RVDD_FE1, U01_BCD1.RVDD_FE2, U01_BCD1.RVDD_FE3, U01_BCD1.RVDD_FE4, U01_BCD2.LVDD_FE1, U01_BCD2.LVDD_FE2, U01_BCD2.LVDD_FE3, U01_BCD2.LVDD_FE4, U01_BCD2.RVDD_FE1, U01_BCD2.RVDD_FE2, U01_BCD2.RVDD_FE3, U01_BCD2.RVDD_FE4
/VSS10: C21.1, C22.1, C23.1, C24.1, C25.1, C26.1, J3.54, U01_BCD1.M10_L, U01_BCD1.M10_R, U01_BCD2.M10_L, U01_BCD2.M10_R


Board: 10 copper layers, 22.0 x 17.0 mm, 54 parts (1 on the bottom side), 50 nets.

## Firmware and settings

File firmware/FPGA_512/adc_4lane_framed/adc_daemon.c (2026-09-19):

/* adc_daemon.c — continuous receiver for the 4-lane framed ADC stream
 *
 * Owns the FT600 exclusively and runs forever:
 *
 *   [USB reader thread]  FT_ReadPipe 0x82 -> 256 MB SPSC byte ring
 *   [decoder thread]     ring -> frame decode -> 512-sample slices
 *                          -> optional WAV recording (any channel subset)
 *                          -> publish ring (last ~2 s of all 512 channels)
 *   [control server]     Unix socket /tmp/adc_daemon.sock, line-based text:
 *       cmd <name>                   board command (chip-reset, fe-on, spi, ...)
 *       record start <path> <chans>  chans = "all" | "0-63,320,384-447"
 *       record stop
 *       stats
 *       plot <chans> <decim>         switch connection to binary plot stream
 *       quit                         shut the daemon down
 *     Async events pushed to all text clients: "!drops lane=2 n=5 total=37"
 *
 * Design constraints (hardware-verified, see docs/FRAMING_SPEC.txt and
 * wave_record.c):
 *   - the read loop must never stall > ~1-2 ms or the FPGA drops samples
 *     (reported via the LANE_ID drop nibble); hence reader thread does
 *     nothing but FT_ReadPipe -> ring.
 *   - table-driven CRC-12 required to sustain 16.5 MB/s.
 *   - startup flush must tolerate empty reads (pipe is empty right after
 *     FT_SetStreamPipe).
 *
 * Frame: {F,SYNC}{E,LANE_ID}{D,CYCLE_CNT}{0,DATA}x128{C,CRC-12}
 * LANE_ID payload {hi,~hi}, hi = {drop_cnt[3:0], lane[1:0]}.
 * Channel map: wav_ch = line*64 + amp, line = 2*lane + odd (D1..D8 - 1).
 */
#include <stdio.h>
#include <stdlib.h>
#include <string.h>
#include <stdint.h>
#include <stdarg.h>
#include <stdatomic.h>
#include <pthread.h>
#include <unistd.h>
#include <errno.h>
#include <signal.h>
#include <time.h>
#include <sys/socket.h>
#include <sys/un.h>
#include <sys/stat.h>
/* Official FTDI D3XX header (/usr/local/include) — needed for the
 * overlapped/async read API; the local minimal ftd3xx.h lacks it. */
#include <ftd3xx.h>

#define SOCK_PATH    "/tmp/adc_daemon.sock"
/* 512 KB stream/read size: reads still return partial data as it arrives,
 * but larger queued transfers let the xHCI controller keep DMA-ing through
 * multi-ms host scheduler stalls (each transfer completion is a submission
 * point where a starved D3XX worker thread would otherwise idle the bus). */
#define CHUNK_SIZE   (512 * 1024)
#define FLUSH_BYTES  (512 * 1024)
#define RING_BYTES   ((size_t)256 * 1024 * 1024)   /* ~15 s @ 16.5 MB/s */

#define N_CHANNELS   512
#define SAMPLE_RATE  15625
#define PUB_SLICES   32768        /* publish ring: ~2.1 s of all channels */

#define MAX_CLIENTS  8
#define EVQ_LEN      64
#define EV_MAXLEN    128

/* ---- CRC-12 ITU-T (poly 0x80F), table-driven (matches usb_framer) ---- */
static unsigned short crc_tab[4096];

static void crc12_init(void) {
    for (int x = 0; x < 4096; x++) {
        unsigned short crc = (unsigned short)x;
        for (int i = 0; i < 12; i++)
            crc = (crc & 0x800) ? ((crc << 1) ^ 0x80F) & 0xFFF
                                : (crc << 1) & 0xFFF;
        crc_tab[x] = crc;
    }
}

static inline unsigned short crc12(unsigned short crc, unsigned short word) {
    return crc_tab[(crc ^ word) & 0xFFF];
}

/* ======================================================================
 * Global state
 * ====================================================================== */
static FT_HANDLE ft = NULL;
static FILE     *replay_fp = NULL;   /* non-NULL = file replay mode */
static pthread_mutex_t ft_wr_mtx = PTHREAD_MUTEX_INITIALIZER; /* pipe 0x02 */
static volatile sig_atomic_t running = 1;

/* ---- SPSC byte ring: reader thread -> decoder thread ----------------- */
static uint8_t *ring;
static _Atomic size_t ring_head;   /* write index (reader)  */
static _Atomic size_t ring_tail;   /* read index  (decoder) */
static _Atomic size_t ring_overruns;

/* ---- stats (decoder-owned; read racily by control threads: counters
 * are word-sized and monotonic, so torn reads are harmless) ------------ */
typedef struct {
    size_t frames, crc_err, seq_gap, lane_id_err, drops;
    unsigned short last_cnt;
    int have_cnt;
} lane_t;
static lane_t lanes[4];
static size_t total_read_bytes, slices_total, partial_slices, filler_slices;
static size_t hunt_drops;
static struct timespec t_start;

/* ---- publish ring: last PUB_SLICES slices of all 512 channels -------- */
static int16_t (*pub_buf)[N_CHANNELS];
static _Atomic uint64_t pub_wpos;    /* total slices ever published */

/* ---- recording -------------------------------------------------------- */
static pthread_mutex_t rec_mtx = PTHREAD_MUTEX_INITIALIZER;
static FILE    *rec_file = NULL;
static char     rec_path[512];
static uint16_t rec_chans[N_CHANNELS];
static int      rec_nch = 0;
static size_t   rec_slices = 0;
static size_t   rec_err0, rec_drop0;         /* totals at record start */
static time_t   rec_start_time;

/* ---- control clients --------------------------------------------------
 * Each text-mode client has an event queue drained by its own thread. */
typedef struct {
    int  fd;
    int  in_use;
    int  plot_mode;                  /* binary stream: no text events */
    char evq[EVQ_LEN][EV_MAXLEN];
    int  ev_head, ev_tail;           /* head=write, tail=read */
    pthread_mutex_t mtx;
    pthread_cond_t  cond;
} client_t;
static client_t clients[MAX_CLIENTS];
static pthread_mutex_t clients_mtx = PTHREAD_MUTEX_INITIALIZER;

static void event_broadcast(const char *fmt, ...)
    __attribute__((format(printf, 1, 2)));

static void event_broadcast(const char *fmt, ...) {
    char line[EV_MAXLEN];
    va_list ap;
    va_start(ap, fmt);
    vsnprintf(line, sizeof line, fmt, ap);
    va_end(ap);

    pthread_mutex_lock(&clients_mtx);
    for (int i = 0; i < MAX_CLIENTS; i++) {
        client_t *c = &clients[i];
        if (!c->in_use || c->plot_mode) continue;
        pthread_mutex_lock(&c->mtx);
        int next = (c->ev_head + 1) % EVQ_LEN;
        if (next != c->ev_tail) {              /* drop event if queue full */
            snprintf(c->evq[c->ev_head], EV_MAXLEN, "%s", line);
            c->ev_head = next;
            pthread_cond_signal(&c->cond);
        }
        pthread_mutex_unlock(&c->mtx);
    }
    pthread_mutex_unlock(&clients_mtx);
}

/* ======================================================================
 * Thread 1: USB reader — FT_ReadPipe -> ring, nothing else
 * ====================================================================== */
static void ring_push(const UCHAR *buf, size_t xfer) {
    size_t head = atomic_load_explicit(&ring_head, memory_order_relaxed);
    size_t tail = atomic_load_explicit(&ring_tail, memory_order_acquire);
    if (RING_BYTES - (head - tail) < xfer) {
        /* host-side overrun: decoder fell > RING_BYTES behind */
        atomic_fetch_add_explicit(&ring_overruns, 1, memory_order_relaxed);
        return;
    }
    size_t off = head % RING_BYTES;
    size_t first = RING_BYTES - off;
    if (first > xfer) first = xfer;
    memcpy(ring + off, buf, first);
    if (xfer > first) memcpy(ring, buf + first, xfer - first);
    atomic_store_explicit(&ring_head, head + xfer, memory_order_release);
    total_read_bytes += xfer;
}

/* ---- reader gap instrumentation (reader-owned; read racily by stats).
 * A 64 KB chunk completes every ~3.97 ms at 16.5 MB/s; a much larger
 * completion-to-completion gap means the bus went idle and the FPGA may
 * have dropped.  out_ms = time spent outside FT_ReadPipe (ring_push +
 * loop overhead) — separates our stalls from library/USB stalls. */
#define GAP_LOG_LEN 32
typedef struct { double t_s, gap_ms, out_ms; unsigned xfer; } gap_rec_t;
static gap_rec_t gap_log[GAP_LOG_LEN];
static unsigned  gap_log_n;                       /* total logged */
static size_t    gap_cnt[4];                      /* >1.5, >3, >6, >12 ms */
static double    gap_max_ms, out_max_ms;

static void *reader_thread(void *arg) {
    (void)arg;
    static UCHAR buf[CHUNK_SIZE];
    ULONG xfer;

    /* ---- File replay mode ---- */
    if (replay_fp) {
        while (running) {
            size_t n = fread(buf, 1, CHUNK_SIZE, replay_fp);
            if (n == 0) {
                rewind(replay_fp);       /* loop forever */
                continue;
            }
            ring_push(buf, n);
            /* Pace to ~16.5 MB/s so the decoder/UI run at real-time */
            usleep((unsigned)(n / 16.5));
        }
        return NULL;
    }

    /* ---- Hardware mode ---- */
#ifdef __APPLE__
    /* The FPGA drops samples if this thread stalls > ~1-2 ms; keep it out
     * of the background/utility QoS bands under load. */
    pthread_set_qos_class_self_np(QOS_CLASS_USER_INTERACTIVE, 0);
#endif

    /* Startup flush: pipe may be empty right after FT_SetStreamPipe, so
     * tolerate empty reads instead of breaking on the first xfer==0. */
    size_t flushed = 0;
    int empties = 0;
    while (running && flushed < FLUSH_BYTES && empties < 4) {
        xfer = 0;
        FT_ReadPipe(ft, 0x82, buf, CHUNK_SIZE, &xfer, 500);
        if (xfer == 0) empties++;
        else { empties = 0; flushed += xfer; }
    }

    /* Synchronous stream loop, as hardware-proven in wave_record. (The
     * library's async API — FT_ReadPipeAsync/FT_GetOverlappedResult — was
     * tried and is broken in libftd3xx 1.1.7 on macOS: completions return
     * FT_IO_ERROR with valid data, then the pipe wedges. The inter-call
     * bus-idle gap costs ~1 dropped sample/s/lane at 16.5 MB/s line rate;
     * drops are counted and reported, never silent.) */
    struct timespec ts_prev, ts0, ts1;
    clock_gettime(CLOCK_MONOTONIC, &ts_prev);
    while (running) {
        clock_gettime(CLOCK_MONOTONIC, &ts0);
        xfer = 0;
        FT_STATUS st = FT_ReadPipe(ft, 0x82, buf, CHUNK_SIZE, &xfer, 3000);
        clock_gettime(CLOCK_MONOTONIC, &ts1);

        double out_ms = (ts0.tv_sec - ts_prev.tv_sec) * 1e3 +
                        (ts0.tv_nsec - ts_prev.tv_nsec) * 1e-6;
        double gap_ms = (ts1.tv_sec - ts_prev.tv_sec) * 1e3 +
                        (ts1.tv_nsec - ts_prev.tv_nsec) * 1e-6;
        ts_prev = ts1;
        if (out_ms > out_max_ms) out_max_ms = out_ms;
        if (gap_ms > gap_max_ms) gap_max_ms = gap_ms;
        if (gap_ms > 1.5) {
            gap_cnt[0]++;
            if (gap_ms > 3.0)  gap_cnt[1]++;
            if (gap_ms > 6.0)  gap_cnt[2]++;
            if (gap_ms > 12.0) gap_cnt[3]++;
            gap_rec_t *g = &gap_log[gap_log_n % GAP_LOG_LEN];
            g->t_s = (ts1.tv_sec - t_start.tv_sec) +
                     (ts1.tv_nsec - t_start.tv_nsec) * 1e-9;
            g->gap_ms = gap_ms;
            g->out_ms = out_ms;
            g->xfer = (unsigned)xfer;
            gap_log_n++;
        }

        if (st != FT_OK && st != FT_TIMEOUT) {
            event_broadcast("!usb read error status=%d", (int)st);
            usleep(100000);
            continue;
        }
        if (xfer) ring_push(buf, xfer);
    }
    return NULL;
}

/* ======================================================================
 * Thread 2: decoder — ring -> frames -> slices -> record/publish
 * ====================================================================== */
static int16_t  slice[N_CHANNELS];
static int      slice_cnt = -1;
static unsigned slice_mask = 0;
static int      last_flush_cnt = -1;

static void slice_publish(const int16_t *s) {
    uint64_t w = atomic_load_explicit(&pub_wpos, memory_order_relaxed);
    memcpy(pub_buf[w % PUB_SLICES], s, N_CHANNELS * sizeof(int16_t));
    atomic_store_explicit(&pub_wpos, w + 1, memory_order_release);

    pthread_mutex_lock(&rec_mtx);
    if (rec_file) {
        int16_t row[N_CHANNELS];
        for (int i = 0; i < rec_nch; i++)
            row[i] = s[rec_chans[i]];
        fwrite(row, sizeof(int16_t), rec_nch, rec_file);
        rec_slices++;
    }
    pthread_mutex_unlock(&rec_mtx);
    slices_total++;
}

static void slice_flush(void) {
    if (slice_cnt < 0) return;
    slice_publish(slice);
    if (slice_mask != 0xF) partial_slices++;
    last_flush_cnt = slice_cnt;
    slice_cnt = -1;
    slice_mask = 0;
}

static void slice_commit(int lane, unsigned short cnt,
                         const unsigned short data[128]) {
    if (slice_cnt >= 0 && cnt != (unsigned short)slice_cnt)
        slice_flush();
    if (slice_cnt < 0) {
        if (last_flush_cnt >= 0) {
            unsigned gap = (cnt - last_flush_cnt - 1) & 0xFFF;
            if (gap > 0 && gap < 2048) {
                static const int16_t zero[N_CHANNELS];
                for (unsigned g = 0; g < gap; g++) {
                    slice_publish(zero);
                    filler_slices++;
                }
            }
        }
        slice_cnt = cnt;
        memset(slice, 0, sizeof(slice));     /* 0 = midscale fill */
    }
    for (int w = 0; w < 128; w++) {
        int line = 2 * lane + (w & 1);
        int amp  = w >> 1;
        slice[line * 64 + amp] = (int16_t)(((int)data[w] - 2048) << 4);
    }
    slice_mask |= 1u << lane;
    if (slice_mask == 0xF)
        slice_flush();
}

static void *decoder_thread(void *arg) {
    (void)arg;
    unsigned short sync_word[4], crc_seed[4];
    for (int l = 0; l < 4; l++) {
        sync_word[l] = 0xFA35 + 0x0111 * l;
        crc_seed[l]  = crc12(0, sync_word[l] & 0xFFF);
    }

    int state = 0;                 /* 0=HUNT, 1=FRAME */
    int wptr = 0, cur = 0;
    unsigned short crc_acc = 0, frame_cnt = 0;
    unsigned short frame_data[128];
    uint8_t carry = 0;             /* odd trailing byte between chunks */
    int have_carry = 0;

    while (running) {
        size_t head = atomic_load_explicit(&ring_head, memory_order_acquire);
        size_t tail = atomic_load_explicit(&ring_tail, memory_order_relaxed);
        size_t avail = head - tail;
        if (avail == 0) { usleep(1000); continue; }
        if (avail > CHUNK_SIZE) avail = CHUNK_SIZE;

        static uint8_t buf[CHUNK_SIZE + 1];
        size_t n = 0;
        if (have_carry) { buf[n++] = carry; have_carry = 0; }
        size_t off = tail % RING_BYTES;
        size_t first = RING_BYTES - off;
        if (first > avail) first = avail;
        memcpy(buf + n, ring + off, first);
        if (avail > first) memcpy(buf + n + first, ring, avail - first);
        n += avail;
        atomic_store_explicit(&ring_tail, tail + avail, memory_order_release);

        if (n & 1) { carry = buf[n - 1]; have_carry = 1; n--; }

        size_t nw = n / 2;
        for (size_t i = 0; i < nw; i++) {
            unsigned short w = buf[i*2] | (buf[i*2+1] << 8);
            unsigned short val = w & 0xFFF;

            if (state == 0) {
                int found = -1;
                for (int l = 0; l < 4; l++)
                    if (w == sync_word[l]) { found = l; break; }
                if (found >= 0) {
                    cur = found; state = 1; wptr = 1;
                    crc_acc = crc_seed[cur];
                } else {
                    hunt_drops++;
                }
            } else {
                if (wptr == 1) {
                    /* {4'hE, hi[5:0], ~hi[5:0]}, hi = {drops, lane} */
                    unsigned hi = (w >> 6) & 0x3F, lo = w & 0x3F;
                    if ((w >> 12) != 0xE || lo != ((~hi) & 0x3F) ||
                        (int)(hi & 0x3) != cur) {
                        lanes[cur].lane_id_err++;
                        event_broadcast("!lane_id lane=%d total=%zu",
                                        cur, lanes[cur].lane_id_err);
                    } else if (hi >> 2) {
                        lanes[cur].drops += hi >> 2;
                        event_broadcast("!drops lane=%d n=%u total=%zu",
                                        cur, hi >> 2, lanes[cur].drops);
                    }
                    crc_acc = crc12(crc_acc, val);
                } else if (wptr == 2) {
                    crc_acc = crc12(crc_acc, val);
                    if (lanes[cur].have_cnt &&
                        ((lanes[cur].last_cnt + 1) & 0xFFF) != val) {
                        lanes[cur].seq_gap++;
                        event_broadcast("!seq lane=%d total=%zu",
                                        cur, lanes[cur].seq_gap);
                    }
                    lanes[cur].last_cnt = val;
                    lanes[cur].have_cnt = 1;
                    frame_cnt = val;
                } else if (wptr <= 130) {
                    crc_acc = crc12(crc_acc, val);
                    frame_data[wptr - 3] = val;
                } else {
                    /* wptr == 131: CRC — commit only if clean */
                    if (val != crc_acc) {
                        lanes[cur].crc_err++;
                        event_broadcast("!crc lane=%d total=%zu",
                                        cur, lanes[cur].crc_err);
                    } else {
                        slice_commit(cur, frame_cnt, frame_data);
                    }
                    lanes[cur].frames++;
                    state = 0;
                }
                wptr++;
                if (wptr > 131) state = 0;
            }
        }
    }
    return NULL;
}

/* ======================================================================
 * WAV recording (header layout as wave_record.c, N channels)
 * ====================================================================== */
static void wr_u16(FILE *f, uint16_t v) { fputc(v & 0xFF, f); fputc(v >> 8, f); }
static void wr_u32(FILE *f, uint32_t v) {
    fputc(v & 0xFF, f); fputc((v >> 8) & 0xFF, f);
    fputc((v >> 16) & 0xFF, f); fputc((v >> 24) & 0xFF, f);
}

static void wav_write_header(FILE *f, int nch, uint32_t data_bytes) {
    fseek(f, 0, SEEK_SET);
    fwrite("RIFF", 1, 4, f);
    wr_u32(f, 36 + data_bytes);
    fwrite("WAVE", 1, 4, f);
    fwrite("fmt ", 1, 4, f);
    wr_u32(f, 16);
    wr_u16(f, 1);                               /* PCM */
    wr_u16(f, (uint16_t)nch);
    wr_u32(f, SAMPLE_RATE);
    wr_u32(f, (uint32_t)SAMPLE_RATE * nch * 2);
    wr_u16(f, (uint16_t)(nch * 2));
    wr_u16(f, 16);
    fwrite("data", 1, 4, f);
    wr_u32(f, data_bytes);
}

/* Parse "all" or "3,5-9,320" into rec-style channel array. Returns count
 * or -1 on syntax error. Channels are clamped/validated to 0..511. */
static int parse_chans(const char *s, uint16_t *out, int max) {
    if (strcmp(s, "all") == 0) {
        for (int i = 0; i < N_CHANNELS && i < max; i++) out[i] = (uint16_t)i;
        return N_CHANNELS < max ? N_CHANNELS : max;
    }
    int n = 0;
    const char *p = s;
    while (*p) {
        char *end;
        long a = strtol(p, &end, 10);
        if (end == p || a < 0 || a >= N_CHANNELS) return -1;
        long b = a;
        p = end;
        if (*p == '-') {
            b = strtol(p + 1, &end, 10);
            if (end == p + 1 || b < a || b >= N_CHANNELS) return -1;
            p = end;
        }
        for (long c = a; c <= b; c++) {
            if (n >= max) return -1;
            out[n++] = (uint16_t)c;
        }
        if (*p == ',') p++;
        else if (*p) return -1;
    }
    return n > 0 ? n : -1;
}

static size_t err_total(void) {
    size_t t = 0;
    for (int l = 0; l < 4; l++)
        t += lanes[l].crc_err + lanes[l].seq_gap + lanes[l].lane_id_err;
    return t;
}
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
int main(int argc, char *argv[]) {
    crc12_init();
    signal(SIGINT, on_signal);
    signal(SIGTERM, on_signal);
    signal(SIGPIPE, SIG_IGN);

    /* --file <path>: replay a raw USB capture instead of live hardware */
    const char *replay_path = NULL;
    for (int i = 1; i < argc - 1; i++) {
        if (strcmp(argv[i], "--file") == 0)
            replay_path = argv[++i];
    }

    ring = malloc(RING_BYTES);
    pub_buf = malloc((size_t)PUB_SLICES * N_CHANNELS * sizeof(int16_t));
    if (!ring || !pub_buf) { perror("malloc"); return 1; }
    memset(pub_buf, 0, (size_t)PUB_SLICES * N_CHANNELS * sizeof(int16_t));

    for (int i = 0; i < MAX_CLIENTS; i++) {
        pthread_mutex_init(&clients[i].mtx, NULL);
        pthread_cond_init(&clients[i].cond, NULL);
    }

    if (replay_path) {
        replay_fp = fopen(replay_path, "rb");
        if (!replay_fp) { perror(replay_path); return 1; }
        printf("adc_daemon: replay mode from %s\n", replay_path);
    } else {
        /* FT600 */
        DWORD devcnt = 0;
        FT_CreateDeviceInfoList(&devcnt);
        if (devcnt == 0) { fprintf(stderr, "No FT600 devices\n"); return 1; }
        if (FT_Create(0, FT_OPEN_BY_INDEX, &ft) != FT_OK) {
            fprintf(stderr, "FT_Create failed (device busy?)\n"); return 1;
        }
        FT_SetPipeTimeout(ft, 0x82, 3000);
        if (FT_SetStreamPipe(ft, FALSE, FALSE, 0x82, CHUNK_SIZE) != FT_OK) {
            fprintf(stderr, "SetStreamPipe failed\n");
            FT_Close(ft);
            return 1;
        }
    }

    /* control socket */
    unlink(SOCK_PATH);
    int srv = socket(AF_UNIX, SOCK_STREAM, 0);
    struct sockaddr_un addr = { .sun_family = AF_UNIX };
    snprintf(addr.sun_path, sizeof addr.sun_path, "%s", SOCK_PATH);
    if (bind(srv, (struct sockaddr *)&addr, sizeof addr) < 0 ||
        listen(srv, 8) < 0) {
        perror(SOCK_PATH);
        return 1;
    }

    clock_gettime(CLOCK_MONOTONIC, &t_start);
    printf("adc_daemon: streaming on %s (512 ch @ %d Hz)\n",
           SOCK_PATH, SAMPLE_RATE);
    fflush(stdout);

    pthread_t th_rd, th_dec, th_srv;
    pthread_create(&th_rd, NULL, reader_thread, NULL);
    pthread_create(&th_dec, NULL, decoder_thread, NULL);
    pthread_create(&th_srv, NULL, server_thread, &srv);

    while (running) usleep(200000);

    /* shutdown: stop recording cleanly, release USB */
    char msg[700];
    record_stop(msg, sizeof msg);
    close(srv);
    unlink(SOCK_PATH);
    pthread_join(th_rd, NULL);
    pthread_join(th_dec, NULL);
    if (replay_fp) {
        fclose(replay_fp);
    } else {
        FT_ClearStreamPipe(ft, FALSE, FALSE, 0x82);
        FT_Close(ft);
    }
    printf("adc_daemon: stopped\n");
    return 0;
}

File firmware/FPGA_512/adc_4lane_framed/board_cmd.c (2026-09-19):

/* board_cmd.c — send commands to the 4-lane FPGA board
 *
 * Writes 2-byte commands on pipe 0x02 (byte 0 = opcode, byte 1 = payload):
 *
 * Simple commands (payload = 0):
 *   chip-reset  0x11  pulse CB_CHIP_RESET (~62 ns)
 *   fe-pulse    0x21  pulse CB_FE_RESET   (~62 ns)
 *   fe-on       0x22  hold CB_FE_RESET high (test mode -> ~2048 midscale)
 *   fe-off      0x23  CB_FE_RESET low (normal operation — the boot default)
 *   pattern-on  0x31  replace ADC data with per-channel +1 ramp
 *   pattern-off 0x32  back to real ADC data
 *
 * Multi-step commands:
 *   spi-load <csv>    load L/R SPI data from CSV, then execute (500 kHz)
 *   stim <N>          run N stimulation cycles (STIM_EN + CLK + CHB sequence)
 */
#include <stdio.h>
#include <stdlib.h>
#include <string.h>
#include <unistd.h>
#include "ftd3xx.h"

static const struct { const char *name; unsigned char op; const char *desc; } cmds[] = {
    { "chip-reset", 0x11, "pulse CB_CHIP_RESET" },
    { "fe-pulse",   0x21, "pulse CB_FE_RESET" },
    { "fe-on",      0x22, "CB_FE_RESET = 1 (test mode, midscale)" },
    { "fe-off",     0x23, "CB_FE_RESET = 0 (normal operation)" },
    { "pattern-on", 0x31, "inject +1 ramp in place of ADC data" },
    { "pattern-off",0x32, "real ADC data (normal)" },
};
#define N_CMDS (sizeof(cmds) / sizeof(cmds[0]))

static void usage(void) {
    printf("Usage: board_cmd <command> [args]\n\n");
    printf("Simple commands:\n");
    for (size_t i = 0; i < N_CMDS; i++)
        printf("  %-11s %s\n", cmds[i].name, cmds[i].desc);
    printf("\nSPI commands:\n");
    printf("  spi              default SPI init (4096 zero-data clocks + latch)\n");
    printf("  spi-load <csv>   load L/R SPI config from CSV and execute\n");
    printf("\nSTIM commands:\n");
    printf("  stim <N>         run N stimulation cycles\n");
}

/* Send a 2-byte command: {opcode, payload} */
static int send_cmd(FT_HANDLE h, unsigned char op, unsigned char payload) {
    UCHAR buf[2] = { op, payload };
    ULONG wr = 0;
    FT_STATUS st = FT_WritePipe(h, 0x02, buf, 2, &wr, NULL);
    return (st == FT_OK && wr == 2) ? 0 : -1;
}

/* ======================================================================
 * SPI CSV loader
 *
 * CSV format: BIT,L,R  (header line, then one row per bit)
 * BIT = bit index (0-based), L = 0|1, R = 0|1
 * Packs bits MSB-first into bytes: BIT 0 → byte 0 bit 7.
 * ====================================================================== */
#define SPI_MAX_BITS 4096
#define SPI_MAX_BYTES (SPI_MAX_BITS / 8)

static int spi_load(FT_HANDLE h, const char *csv_path) {
    FILE *f = fopen(csv_path, "r");
    if (!f) { perror(csv_path); return -1; }

    unsigned char l_data[SPI_MAX_BYTES];
    unsigned char r_data[SPI_MAX_BYTES];
    memset(l_data, 0, sizeof l_data);
    memset(r_data, 0, sizeof r_data);

    char line[256];
    int max_bit = -1;

    /* Skip header */
    if (!fgets(line, sizeof line, f)) { fclose(f); return -1; }

    while (fgets(line, sizeof line, f)) {
        int bit, lv, rv;
        if (sscanf(line, "%d,%d,%d", &bit, &lv, &rv) != 3) continue;
        if (bit < 0 || bit >= SPI_MAX_BITS) continue;
        int byte_idx = bit / 8;
        int bit_pos  = 7 - (bit % 8);   /* MSB-first packing */
        if (lv) l_data[byte_idx] |= (1 << bit_pos);
        if (rv) r_data[byte_idx] |= (1 << bit_pos);
        if (bit > max_bit) max_bit = bit;
    }
    fclose(f);

    if (max_bit < 0) {
        printf("No valid rows in %s\n", csv_path);
        return -1;
    }
    int total_bits = max_bit + 1;
    int n_bytes = (total_bits + 7) / 8;
    printf("Loaded %d bits from %s (%d bytes per channel)\n",
           total_bits, csv_path, n_bytes);

    /* Reset BRAM write pointers */
    if (send_cmd(h, 0x42, 0) < 0) return -1;

    /* Load L channel */
    for (int i = 0; i < n_bytes; i++)
        if (send_cmd(h, 0x43, l_data[i]) < 0) return -1;

    /* Load R channel */
    for (int i = 0; i < n_bytes; i++)
        if (send_cmd(h, 0x44, r_data[i]) < 0) return -1;

    /* Set bit count (low byte first, then high byte latches both) */
    if (send_cmd(h, 0x45, total_bits & 0xFF) < 0) return -1;
    if (send_cmd(h, 0x46, (total_bits >> 8) & 0xFF) < 0) return -1;

    /* Execute SPI sequence */
    if (send_cmd(h, 0x41, 0) < 0) return -1;

    printf("SPI programming started (%d bits @ 500 kHz = %.1f ms)\n",
           total_bits, total_bits * 2.0 / 1000.0);
    return 0;
}

/* ======================================================================
 * Main
 * ====================================================================== */
int main(int argc, char *argv[]) {
    if (argc < 2) { usage(); return 1; }

    /* Check for simple commands first */
    unsigned char op = 0;
    for (size_t i = 0; i < N_CMDS; i++)
        if (strcmp(argv[1], cmds[i].name) == 0) op = cmds[i].op;

    int is_spi      = (strcmp(argv[1], "spi") == 0);
    int is_spi_load = (strcmp(argv[1], "spi-load") == 0);
    int is_stim     = (strcmp(argv[1], "stim") == 0);

    if (op == 0 && !is_spi && !is_spi_load && !is_stim) { usage(); return 1; }
    if (is_spi_load && argc < 3) {
        printf("Usage: board_cmd spi-load <csv_file>\n"); return 1;
    }
    if (is_stim && argc < 3) {
        printf("Usage: board_cmd stim <N>  (N = 1..255)\n"); return 1;
    }

    DWORD devcnt = 0;
    FT_CreateDeviceInfoList(&devcnt);
    if (devcnt == 0) { printf("No devices\n"); return 1; }

    FT_HANDLE h = NULL;
    if (FT_Create(0, FT_OPEN_BY_INDEX, &h) != FT_OK) {
        printf("FT_Create failed\n");
        return 1;
    }

    int rc = 0;
    if (op != 0) {
        /* Simple command */
        rc = send_cmd(h, op, 0);
        if (rc == 0) printf("Sent %s (0x%02X)\n", argv[1], op);
        else         printf("Command write failed\n");
    } else if (is_spi) {
        /* Default SPI: 4096 zero-data clocks + latch (BRAM powers up to 0) */
        rc = send_cmd(h, 0x45, 0x00);           /* bit count [7:0] = 0 */
        if (rc == 0) rc = send_cmd(h, 0x46, 0x10); /* bit count [11:8] = 0x10 → 4096 */
        if (rc == 0) rc = send_cmd(h, 0x41, 0x00); /* execute */
        if (rc == 0) printf("Default SPI init started (4096 clocks @ 500 kHz)\n");
        else         printf("Command write failed\n");
    } else if (is_spi_load) {
        rc = spi_load(h, argv[2]);
    } else if (is_stim) {
        int n = atoi(argv[2]);
        if (n < 1 || n > 255) {
            printf("Stim count must be 1..255\n"); rc = 1;
        } else {
            rc = send_cmd(h, 0x60, (unsigned char)n);
            if (rc == 0) printf("Started stim sequence (%d reps)\n", n);
            else         printf("Command write failed\n");
        }
    }

    FT_Close(h);
    return rc ? 1 : 0;
}

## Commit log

2026-09-19 Organize FPGA 4K project sources, current decisions, and agent onboarding
    [Howard_FPGA_Rev2_60x70.kicad_pcb, PCB.kicad_pcb, PCB.kicad_sch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]
2026-09-19 Limit shared collection to Gerald and team source material
    [Howard_FPGA_Rev2_60x70.kicad_pcb, Routing_1_Group_Size_Study.kicad_pcb, Routing_1_Group_Size_Study_placements.csv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]
2026-09-19 Include original FPGA source files and organize documentation by topic
    [logic_anayzer1.csv, pinout_J32_J33.csv, sine-all-5_decoded.csv]
2026-09-19 Add source-based board views and system overview
2026-09-19 Include the earlier overall headboard assembly model
    [stacked_headboard_original.stl]
2026-09-22 Set up shared PCB workflow and import editable FPGA draft
    [BOM_Draft.csv, Howard_FPGA_Connected_42x40.kicad_pcb, Howard_FPGA_Connected_42x40.kicad_sch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]
2026-10-30 Document the four agreed PCB board names
2026-10-30 Revert "Document the four agreed PCB board names"
    This reverts commit cbb854724d157a36fea906498c9d3b4bd0bdd09e.
